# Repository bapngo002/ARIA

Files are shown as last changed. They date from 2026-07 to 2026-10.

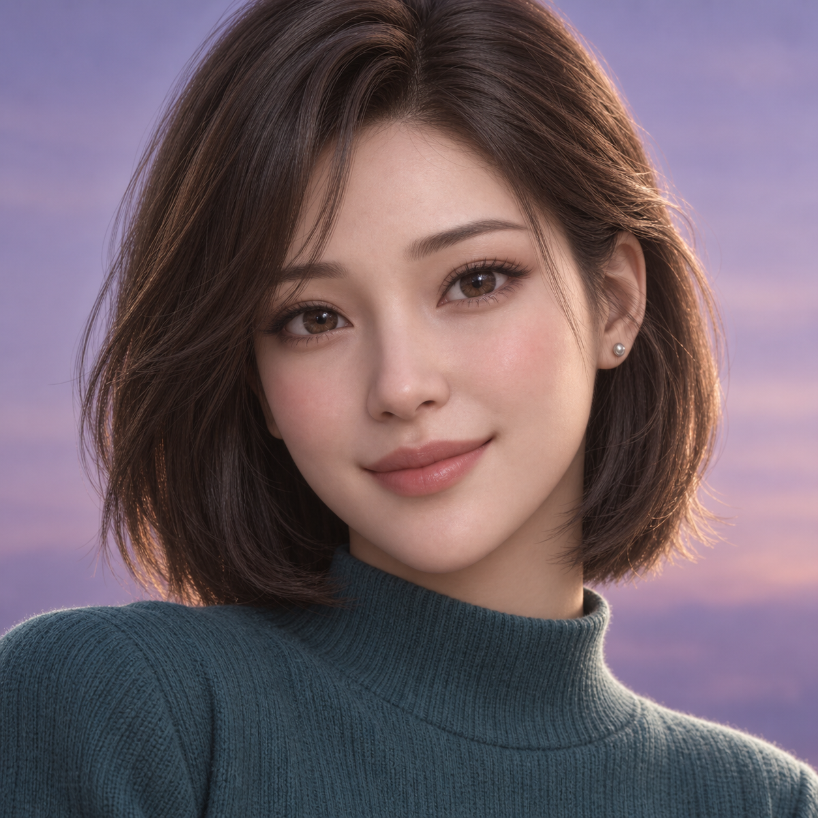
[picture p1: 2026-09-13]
docs/design/aria-face-concepts/03-bob.png

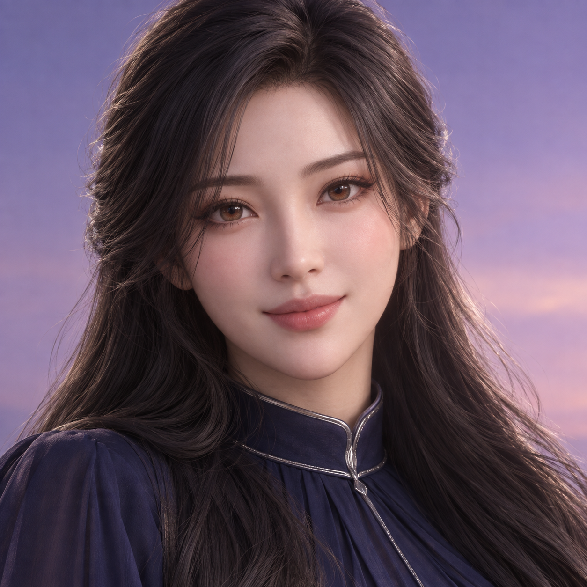
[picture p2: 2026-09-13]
docs/design/aria-face-concepts/01-long-hair.png

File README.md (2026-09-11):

# ARIA

ARIA là dự án robot AI đồng hành cá nhân.

**Bắt đầu tại [ARIA-MASTER-HANDOFF](docs/ARIA-MASTER-HANDOFF.md)**: CURRENT/CANONICAL snapshot, hướng dẫn tài khoản ChatGPT mới, tiến độ kiểm chứng, pinmap, migration gaps và NEXT STEP ORDER. Checkout đã hợp nhất là source of truth làm việc; trạng thái đồng bộ GitHub xem master.

[ARIA-BOM-001](docs/ARIA-BOM-001.md) là nguồn duy nhất cho inventory, model, số lượng, trạng thái mua và CAD. Không suy ra tiến độ từ BOM. CAD/bằng chứng mua hàng nằm trong `purchased-hardware/`.

[PRD](docs/ARIA-PRD-001.md) giữ frozen cho yêu cầu sản phẩm; các ghi chú tiến độ cũ trong đó không thay thế master handoff. Đã nhập 9 file capture Pi/ESP32 nguyên bản; runtime và build vẫn cần xác minh; xem checklist ở master, [firmware](firmware/README.md) và [software](software/README.md).

Dữ liệu ARIA lưu trên ổ D. Repo làm việc: `D:\UserData\ARIA\repo`; chính sách lưu trữ và đường dẫn lịch sử xem master handoff.

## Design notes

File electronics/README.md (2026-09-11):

# ARIA electronics workspace

Native mainboard, schematic and reviewed fabrication work belongs here.

Do not store another component list or CAD library here. Use [`docs/ARIA-BOM-001.md`](../docs/ARIA-BOM-001.md) for the purchased inventory and CAD status.

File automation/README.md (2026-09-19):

# ARIA Automation

Canonical state and architecture: `docs/ARIA-AUTOMATION-CANONICAL.md`.

Runtime state is kept outside Git at `D:\UserData\ARIA\automation-state`.

Phase 1 commands:

```powershell
powershell -NoProfile -ExecutionPolicy Bypass -File .\automation\windows\aria-c2c.ps1 Status
powershell -NoProfile -ExecutionPolicy Bypass -File .\automation\windows\aria-c2c.ps1 Ensure
powershell -NoProfile -ExecutionPolicy Bypass -File .\automation\windows\install-c2c-startup.ps1
powershell -NoProfile -ExecutionPolicy Bypass -File .\automation\tests\test-phase1.ps1
```

Phase 2 one-shot runner:

```powershell
powershell -NoProfile -ExecutionPolicy Bypass -File .\automation\runner\aria-runner.ps1 -TaskText "Review current PRO MAX power state"
powershell -NoProfile -ExecutionPolicy Bypass -File .\automation\runner\aria-runner.ps1 -TaskFile .\task.json
powershell -NoProfile -ExecutionPolicy Bypass -File .\automation\runner\aria-runner.ps1 -ResumeTaskId aria-YYYYMMDDTHHMMSS-xxxxxxxx
powershell -NoProfile -ExecutionPolicy Bypass -File .\automation\tests\test-phase2.ps1
```

Phase 2 task packets are untracked runtime data under `automation/runtime/tasks/<task_id>`. See `automation/runner/README.md` for the state machine and packet contract.

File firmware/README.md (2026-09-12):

# ARIA firmware

Mới 2026-09-13: [ARIA_ENCODER_CHECK_R1](esp32/ARIA_ENCODER_CHECK_R1/README.md) v0.1.0, chỉ kiểm tra encoder phải SDA4/SCL5 trên ESP thay thế. Không chạy motor; giữ nguồn driver ngắt. Encoder trái hỏng để tách khỏi mạch. Đây là bản riêng, không sửa capture dưới đây.

Đã nhập nguyên bản [ARIA_DRIVE_ONLY.ino](esp32/ARIA_DRIVE_ONLY/ARIA_DRIVE_ONLY.ino), banner Drive V0.3. Đây là source capture, chưa xác minh flash hoặc last-known-good. Không sửa pin/tuning hoặc tự flash trong đợt hợp nhất.

[MASTER HANDOFF](../docs/ARIA-MASTER-HANDOFF.md) là nguồn duy nhất cho pinmap, motor PARTIALLY VERIFIED, các nhánh watchdog còn mở và checklist build/bench. Hash nằm trong [capture manifest](../software/capture-manifest.json).

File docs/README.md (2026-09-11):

# ARIA engineering documents

**Đọc [ARIA-MASTER-HANDOFF.md](ARIA-MASTER-HANDOFF.md) trước.** Đây là snapshot CURRENT/CANONICAL về tiến độ, verification, pinmap và migration gaps; checkout đã hợp nhất là source of truth làm việc; trạng thái đồng bộ GitHub xem master.

[`ARIA-BOM-001.md`](ARIA-BOM-001.md) là nguồn chuẩn duy nhất cho inventory, model, số lượng, trạng thái mua và CAD. Không suy diễn tiến độ từ BOM. PRD giữ frozen; ghi chú tiến độ historical trong PRD không phải current-state.

| File | Nội dung |
|---|---|
| `ARIA-MASTER-HANDOFF.md` | CURRENT/CANONICAL tiến độ, bootstrap, evidence, pinmap, gaps và next steps |
| `ARIA-BOM-001.md` | Inventory và CAD canonical |
| `ARIA-PRD-001.md` | Yêu cầu sản phẩm frozen |
| `ARIA-HW-001.md` | Cổng kiểm tra phần cứng |
| `ARIA-MECH-001.md` | Quy tắc cơ khí/CAD |
| `ARIA-PCB-001.md` | Quy tắc phát triển mainboard |
| `ARIA-WIRING-001.md` | Quy tắc đấu dây và an toàn |

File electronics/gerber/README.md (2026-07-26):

# Gerber release directory

Only reviewed fabrication packages belong here. Each release must identify its
source commit, PCB revision, DRC result, and user approval.

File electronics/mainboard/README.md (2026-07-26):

# Mainboard

Native source files for the two-layer ARIA mainboard. Development is governed by
`docs/ARIA-PCB-001.md`.

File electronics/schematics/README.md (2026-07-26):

# Schematics

Reviewed schematic exports, power-tree diagrams, calculations, and design-review
records.

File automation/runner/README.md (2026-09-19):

# ARIA One-Shot Runner — Phase 2

`aria-runner.ps1` is the single Phase 2 intake entrypoint. It accepts one task, creates one durable packet, advances the fixed state machine, and prints one aggregate JSON report. Phase 2 always stops before routing, council, Codex execution, or repository execution.

## Commands

Task text:

```powershell
powershell -NoProfile -ExecutionPolicy Bypass -File .\automation\runner\aria-runner.ps1 -TaskText "Review current PRO MAX power state"
```

The task text can also be positional:

```powershell
powershell -NoProfile -ExecutionPolicy Bypass -File .\automation\runner\aria-runner.ps1 "Review current PRO MAX power state"
```

JSON input:

```json
{
  "user_request": "Review current PRO MAX power state",
  "workspace": "D:\\UserData\\ARIA\\repo",
  "scope": "review"
}
```

```powershell
powershell -NoProfile -ExecutionPolicy Bypass -File .\automation\runner\aria-runner.ps1 -TaskFile .\task.json
```

Resume after interruption or a corrected transient failure:

```powershell
powershell -NoProfile -ExecutionPolicy Bypass -File .\automation\runner\aria-runner.ps1 -ResumeTaskId aria-YYYYMMDDTHHMMSS-xxxxxxxx
```

## Durable packet

Each task is stored under `automation/runtime/tasks/<task_id>/`:

- `task.json`: the normalized request and immutable task digest.
- `checkpoint.json`: authoritative resumable stage state.
- `events.jsonl`: bounded append-only transition evidence; raw task text is not copied here.
- `final-report.json`: the single aggregate output for the latest attempt.

Writes to `task.json`, `checkpoint.json`, and `final-report.json` use same-directory temporary files and atomic replacement. A per-task lock prevents concurrent attempts. The checkpoint is authoritative if power loss occurs between file writes. A resumed invocation verifies the immutable task digest before continuing.

The Phase 2 state machine is fixed in `stage-schema.json`:

```text
RECEIVED -> CONTEXT_LOAD -> PRECHECK -> READY_FOR_ROUTING -> STOP
```

Any failure records `FAILED`, enters `STOP`, preserves the failed stage in `resume_stage`, writes a final report, and exits with code 2. A successful run exits with code 0 and result `READY_FOR_ROUTING`. `STOP` is a boundary in this phase, not permission to route or execute.

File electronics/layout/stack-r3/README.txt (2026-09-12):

ARIA STACK R3 — CONCEPT FOR SOLIDWORKS VIEWING

Open ARIA_STACK_R3_ASSEMBLED_CONCEPT.step or ARIA_STACK_R3_EXPLODED_CONCEPT.step in SolidWorks (File > Open > STEP). Native FreeCAD sources are also provided. Native SLDPRT export was not verified because the installed SolidWorks COM startup did not return; no claim of successful SolidWorks import is made.

Units: mm. Base outline: 70 x 100, confirmed by user. Overall assembled concept envelope: approximately 70 x 120 x 79.6; the additional length is ESP antenna overhang. Layer elevations 0 / 30 / 60 are design assumptions, NOT selected standoff heights. Module blocks, connectors and cooler are representative envelopes, NOT dimensionally validated library parts. The Pi nominal outline and ESP nominal outline are used for illustration, not footprint release. No mounting-hole coordinates are released. The rear Pi support scheme is deliberately incomplete pending actual mounting geometry.

Green: carrier/board. Black: ESP, driver or ground bank. Purple: amplifier. Orange: power-module placeholder. Blue: INA260 or sensor connector. Front banks are physically adjacent but electrically distinct: GND / VBAT / 5V / 3V3_PI / 3V3_ESP. These are not connector part selections or a circuit diagram.

The exploded model raises middle and top levels by 32 and 64 mm beyond their assembled positions. No motion, firmware changes, electrical continuity, thermal/EMI test or assembly-fit release has been performed. All exported shapes passed geometric validity checks; PNGs were visually reviewed. Geometry validity does not prove mechanical fit.

Functional mounts (display, camera, ToF, mic, IMU/environment, battery/motors/speakers) remain outside this electronics-stack concept. INA260 label is visible in the user photo; its arrival/use and wiring are not yet confirmed. Keep the burned board and suspect harness unpowered until incident checks.

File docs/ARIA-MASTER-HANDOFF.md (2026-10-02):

# ARIA — MASTER HANDOFF

## ACTIVE CHECKPOINT - 2026-10-02 S5 HEALTH MANAGER TECHNICAL PASS PC; STOP owner decision

- **Current: S5 HEALTH MANAGER = TECHNICAL_PASS_PC; STOP owner next decision.** HealthManager is the single evidence/normalization/publication owner for APP/AVATAR/VOICE/STT/TTS/AUDIO/CAMERA/ESP/POWER/NETWORK/AI. Seven existing states unchanged; HOLD not implemented.
- **PC proof:** 147 backend + 4 real loopback HTTP health/security + 85 frontend tests PASS; 28 browser cases PASS, including real MaiChi playback/end/cancel -> REST and normalized TTS/AUDIO/VOICE health. Camera delta=0, avatar reload=0, uncaught exceptions=0. No new render loop/canvas/WebGL/health worker/timer.
- **Stress:** 3,000 transition cycles -> 9,000 health events; 10,000 unchanged reports -> 0 events. Retained backend memory +884 bytes, listeners/thread count unchanged, bounded ring256; UI30 cycles DOM347->347/listeners184->184/post-GC nodes958->958.
- **Health policy:** monotonic evidence leases; stale -> UNKNOWN/stale=true; disabled != offline != fault. Nonfatal first failure from HEALTHY grace3s, second DEGRADED, third FAULT; actual success recovers. APP/fatal evidence immediate; explicit POWER danger latched until success. Optional camera/ESP do not fault overall app. HTTP liveness cannot clear composition fault; browser cannot own APP health; fixture reports rejected.
- **Current evidence limits:** APP TTL5s, AVATAR120s, POWER5s, configured ESP1.5s, NETWORK60s, others300s. Avatar readiness has a conservative lease without a new heartbeat. Real physical power/camera/ESP, STT capture, Pi CPU/FPS and service benchmark remain unverified/DEFERRED_PI; not production verified.
- **S4-06 owner decision:** TECHNICAL_PASS_PC / VISUAL_PASS_CONDITIONAL. Hardware Aura visual locked, CAMERA OFFLINE visibility=POLISH_LATER. Production Aura consumes normalized health; labelled health fixtures are frontend-only tests, not telemetry.
- **Evidence/checkpoint:** D:/UserData/ARIA/SPATIAL_OS_WORK/reports/S5-HEALTH-MANAGER/{report.md,checkpoint.json}; captures/S5-HEALTH-MANAGER contains genuine production-health and MaiChi proof plus labelled test fixtures. Source/capture SHA-256 and exact changed-file scope recorded. UI40 and other protected35 hashes unchanged.
- **Preserved:** native primary/default; ZeroWeight experimental; temporary MaiChi RMS voice/Piper retained. No .blend/GLB/master copies or changes, no PCB/ESP transport/firmware/motor action. S5 health code/assets remain LOCAL; only this reviewed checkpoint synchronized. No reset/revert/broad staging.
- **NEXT STEP: STOP. Owner decides next stage; no S6/S7, no Memory Constellation. Pi DEFERRED_PI.**

## Earlier checkpoints - retained as history

## ACTIVE CHECKPOINT - 2026-10-02 S4-06 TECHNICAL PASS PC; VISUAL EVIDENCE READY; STOP owner review

### S4-06 Hardware Aura - TECHNICAL PASS PC - 2026-10-02

- **OWNER DECISION/SCOPE:** S4-05 TECHNICAL_PASS_PC / VISUAL_PASS_CONDITIONAL accepted; freeze accepted Home/Capability Field, POLISH_LATER only. S4-06 only; STOP for owner visual review, NO S4-07. Pi DEFERRED_PI.
- **IMPLEMENTATION:** existing AppStore app.health drives seven bounded SVG arcs POWER/AUDIO/STT/CAMERA/ESP/NETWORK/AI; exact seven aria_state.py health states, unknown/missing/disconnected safe. SYSTEM_AURA semantic layer between CONTEXT/FOREGROUND; context recedes normal arcs, fault remains visible. Hover/tap/keyboard micro info,4200ms auto-dismiss, no permanent text. Real voltage only existing non-mock matching fresh backend power.latest source/schema; absent telemetry no number. STARTING pulse two700ms cycles only on state change; LOW_POWER/reduced motion static/cancel active pulse.
- **VERIFY:**85 targeted tests(17 new+68 retained),3 JS syntax checks;26 aggregate browser cases(16 production+8 edges+2 real MaiChi voice).480x480/720x720/current1536x1039,mouse/touch,all five context ports,30 health cycles DOM349->349/listeners184->184/retained nodes962->962 after GC;heap7020572->7027744 bytes.10 factory destroy/re-init cycles clean. Camera0,avatar reload0,uncaught0,finite morphs,same native canvas/single loop. No new poll/render loop/canvas/WebGL.
- **PRESERVED/LIMITS:**40 protected asset/avatar/voice hashes and28 backend hashes unchanged;36 existing UI sources unchanged; accepted46965-byte S4-05 CSS prefix exact. Three existing UI files(app.js/style.css/spatialLayers.js)+new hardwareAura.js+one test changed; code/assets LOCAL. Native primary,ZeroWeight experimental,MaiChi temporary RMS/Piper fallback retained. Genuine MaiChi playback across five contexts -> end REST;actual Media stop -> cancel REST. Full suite/live STT/camera/physical telemetry/Piper playback/Pi FPS not claimed. One favicon404 console resource error disclosed,0 JS exceptions.
- **EVIDENCE:** D:/UserData/ARIA/SPATIAL_OS_WORK/reports/S4-06/{report.md,checkpoint.json,webgl.json,edges.json,voice.json,preservation.json,scope-audit.json,visual-evidence.json};captures/S4-06/review-sheet-720.png. Seven labelled frontend health fixtures on genuine production app/native GLB plus one actual PC health image; no backend health/telemetry writes. Full720 originals, no crop/filter/color changes.
- **STATUS/NEXT:** TECHNICAL_PASS_PC / VISUAL_EVIDENCE_READY / PENDING_OWNER_REVIEW. STOP here; NO S4-07 or Pi. Review Hardware Aura sheet; small S4-05 polish deferred. Documentation-only reviewed synchronization; preserve dirty tree.

## Earlier checkpoints - retained as history

## ACTIVE CHECKPOINT - 2026-10-02 S4-05 TECHNICAL PASS PC; VISUAL EVIDENCE READY; STOP owner review

### S4-05 Spatial Depth & Visual Language - TECHNICAL PASS PC - 2026-10-02

- **OWNER REVIEW/SCOPE:** IDLE retained as accepted baseline; earlier HOME/CHAT visual FAIL and field-depth FAIL prompted this bounded UI change. S4-01–04 technical PASS retained. No backend/avatar/voice/model/hardware feature opened.
- **RESULT:** latest user/ARIA current-turn strips replace permanent full-history panel; inactive turn DOM removed after20s attention. Explicit history uses same single-owner context lifecycle. Mic command dock tap/type expansion, successful-send collapse, unsent draft retention, max2 transient suggestions. Five asymmetric capability objects have distinct CSS Z-depth/scale/opacity, local material/rims and focus advancement; native camera unchanged. Two static background layers, consistent large avatar, healthy provider text hidden on main.
- **VERIFY:**68 targeted/regression tests+4 syntax checks;34 aggregate browser cases(11 production+23 edge),30-cycle all-port cleanup DOM318->318;480/720/current1536x1039/mouse/touch. Camera0,avatar reload0,uncaught0,finite real blink/gaze/mouth/seven visemes,single native loop. New UI transform/opacity;observed targets max7;LOW_POWER perspective off. Dispatch and voice-state fixtures labelled,not new real audio proof. Native short meter quiet28.44FPS/field~29FPS under retained30FPS cap,NOT Pi/60FPS benchmark.
- **PRESERVED/LIMITS:**40 protected hashes+40 other UI-source hashes unchanged. Six UI source files and one targeted test changed; code/assets LOCAL. Native primary,ZeroWeight experimental,MaiChi temporary RMS/Piper fallback retained. Full suite/live audio/STT/send/camera/media not rerun;favicon404 disclosed separately. Pi DEFERRED_PI. No source/master/runtime change or copy.
- **EVIDENCE/STATUS:**D:/UserData/ARIA/SPATIAL_OS_WORK/reports/S4-05/{report.md,checkpoint.json,webgl.json,edges.json,lifecycle_trace.json,preservation.json,visual-evidence.json};captures/S4-05 eight genuine production720 PNGs+review-sheet-720.png,viewport captures. TECHNICAL_PASS_PC;VISUAL_EVIDENCE_READY;PENDING_OWNER_REVIEW. Agent inspection recorded;NO VISUAL_PASS.
- **NEXT:**STOP for owner review of review-sheet-720.png. NO S4-06/Hardware Aura/Memory Constellation/Pi. Documentation-only reviewed sync; preserve dirty working tree.

## Earlier checkpoints - retained as history

## ACTIVE CHECKPOINT - 2026-10-02 VISUAL EVIDENCE READY; STOP owner review

### S4-03/S4-04 Production Visual Evidence Gate - 2026-10-02

- **STATUS:** S4-03 = TECHNICAL_PASS_PC; S4-04 = TECHNICAL_PASS_PC; VISUAL_APPROVAL_PENDING. VISUAL_EVIDENCE_READY; VISUAL_GATE = PENDING_OWNER_REVIEW. No owner visual PASS claimed.
- **FIX/VERIFY:** Capture helper's serialized DOM lacked getAnimations despite correct element lookup; genuine Chromium154 supports it. Evidence-only feature detection, bounded transition fallback and full Home fade wait added; production UI unchanged.24 real production PNGs at720x720/480x480/current1536x1039, eight requested states each; no DEV overlay/mock/test page.60 lifecycle events: max active1,DOM323->323,empty closed host,avatar reload0/camera delta0/uncaught0/lifecycle errors0,same native canvas/loop. One initial favicon.ico404 disclosed separately.
- **PRESERVED/EVIDENCE:**45 production source hashes unchanged;40 protected hashes match prior checkpoint. Native primary/Mai Chi temporary/Piper fallback retained. Existing technical suites not rerun. D:/UserData/ARIA/SPATIAL_OS_WORK/reports/S4-04/visual-gate.md, visual-capture.json, visual-lifecycle-trace.json; captures/S4-04/visual-gate/{720x720,480x480,current_1536x1039}/01_home_idle.png through08_return_home.png.
- **NEXT:** STOP for owner screenshot review. S4-05/Hardware Aura/new redesign unopened; Pi DEFERRED_PI. Only this reviewed handoff delta published; code/assets remain LOCAL.

## Earlier checkpoints - retained as history

## ACTIVE CHECKPOINT - 2026-10-02 S4-04 all five context ports PASS PC; owner visual pending

Native primary; Mai Chi temporary RMS voice unchanged; no hardware. Code/assets LOCAL; documentation only.

### S4-04 Remaining Capability Context Ports - TECHNICAL PASS PC - 2026-10-02

- **RESULT:** Messages/Camera/Media/Settings now register CONTEXT surfaces through the SAME S4-03 manager, alongside Memory. One host/owner; no new popup, renderer or page navigation. Draft restore for Memory/Messages, app-state for Camera/Media and preferences for Settings. Existing handler/backend mapping retained; unavailable camera stays disabled. No redesign; only capabilityField registry/policy/comment changed in this stage.
- **VERIFY:** 62 targeted/regression tests and58 browser cases PASS: all five at480/720/current2138x1033/360x740; all20 ordered replacements, canonical Escape/Close, draft restore, all-port LISTENING prominence fixtures, production touch/captures. Existing Messages/Camera/Media/Settings handler dispatch isolated locally, without send/capture/external launch/config mutation. Real unchanged Mai Chi playback while replacing all five contexts -> end REST; actual Media surface stop -> cancel REST.0 exceptions/NaN,camera delta0,native reload0 during surface operations; same canvas/render loop.
- **PRESERVED/LIMITS:**40 forbidden hashes exact;8 other S4-03 UI/core hashes unchanged, including lifecycle manager/CSS/apps. S4-03 30-cycle stress/no DOM-listener growth retained;20 new cross-capability replacements cleanup PASS. Native primary, experimental ZeroWeight, temporary Mai Chi RMS-only/Piper fallback, source/master/GLB/backend/hardware unchanged; no source/candidate copy. Owner visual PENDING, Pi DEFERRED_PI; full project suite/live camera/STT/send/media playback not claimed.
- **EVIDENCE/NEXT:** reports/S4-04/{report.md,checkpoint.json,webgl.json,voice.json,lifecycle_trace.json,preservation.json,visual_review.json}; captures/S4-04 all ports/viewport/production-touch/actual voice PNGs. Code/UI LOCAL; reviewed documentation-only sync. Core context lifecycle and five ports technically complete on PC; retain for owner final visual review. No Hardware Aura or Pi task opened.

## Earlier checkpoint records - retained as history

## ACTIVE CHECKPOINT - 2026-10-02 S4-03 Context Lifecycle PASS PC; S4-04 next

Native primary; Mai Chi temporary RMS voice unchanged; no hardware. Code/assets LOCAL; documentation only.

### S4-03 Context Surface Lifecycle - TECHNICAL PASS PC - 2026-10-02

- **RESULT:** spatialSurfaces.js now owns one foreground context through CLOSED/ENTERING/ACTIVE/EXITING/CLOSED, latest-request replacement, canonical Close/Escape/Browser Back and explicit owner/dismiss/restore policies. Listening reduces prominence without deleting draft; no SUSPENDED state required. Finite220ms enter/180ms exit; LOW_POWER120/100ms; reduced motion immediate. Semantic CONTEXT layer sits between retained avatar CENTER alias and foreground/alert layers; no redesign or new renderer.
- **CLEANUP:** closed host body empty; generated Memory rows/listeners released, transition timer/animation/session scope0. Original lightweight form controls/handlers are parked as bounded reusable view templates to preserve drafts; no newly hidden heavy presentation retained or per-open listener added. App-lifetime listeners are abortable on destroy; trace is capped at96 metadata entries.
- **VERIFY:** 62 targeted/regression tests; 71 browser cases PASS, including30 actual-click open/API replace/close cycles,10 rapid sequences, Browser Back, LISTENING/IDLE draft fixture, touch,480/720/current2138x1033, real unchanged Mai Chi WAV speaking/context replace/end/cancel REST.0 JS exceptions/NaN;camera delta0;native reload0 and same canvas/render loops. DOM/listener counters {'documents': 1, 'nodes': 938, 'jsEventListeners': 137} -> {'documents': 1, 'nodes': 938, 'jsEventListeners': 137}; live nodes 338 -> 338; heap delta308648bytes after controlled GC, no linear growth in samples.
- **FIXES/LIMITS:** delayed backend open could reopen during EXITING; UI close intent now begins at EXITING, serial navigation waits for request acknowledgement plus matching state. Real400ms delayed-response proof PASS. Test-only standby/reload reference errors corrected; retained failure evidence.40 forbidden hashes exact; assets/avatar/voice/backend/hardware untouched. Native primary, experimental ZeroWeight, temporary Mai Chi RMS/Piper retained. Owner visual PENDING; Pi DEFERRED_PI; full suite not run, no mic/STT or phoneme timing claim.
- **EVIDENCE/NEXT:** reports/S4-03/{report.md,checkpoint.json,webgl.json,edges.json,lifecycle_trace.json,preservation.json}; captures/S4-03 real context/listening fixture/voice/controls/touch PNGs. Code/assets LOCAL; documentation-only sync. NEXT automatically S4-04 port remaining four capabilities to this same context manager. No Hardware Aura.

## Earlier checkpoint records - retained as history

## ACTIVE CHECKPOINT - 2026-10-02 S4-02 Memory context PASS PC; field retained

Native primary; Mai Chi temporary RMS voice unchanged; no hardware. Code/assets LOCAL; documentation only.

### S4-02 Memory context surface - PASS PC - 2026-10-02

- **RESULT:** S4-01 accepted field retained; Memory now uses a real CONTEXT surface bound to existing AppStore memories/remember controls, rather than web-page navigation. Native avatar remains visible with unchanged accepted camera. Draft stays in its existing input; entry uses finite transform/opacity only. Reading an active context no longer triggers30s standby. Memory composer is fixed in the surface; content/destructive control scroll independently.
- **SAFETY/UX:** existing cancel action is reachable via compact surface stop while busy; no TTS/backend rewrite. Close clears context/active/tint/description and restores focus/home interaction. Existing Messages/Camera/Media/Settings TASK surfaces remain accessible. Alert band reserved below surfaces; footer recedes only when a notice occupies that band, preventing overlap on small circles.
- **VERIFY:** 51 targeted/regression tests,32 actual WebGL context cases+2 final audio/UI+20 final layout cases PASS (54 total),480/720/current1368x1027 and360x740. Real unchanged Mai Chi speaking -> end REST, and actual /api/cancel200 -> tts:end(ok=false) -> mouth/UI REST;31s context reading,touch,draft,reload,cleanup and all five surface selections.0 JS exceptions/NaN;camera delta0;avatar/canvas/load/render-loop unchanged. Remember dispatch and replayed existing alert are labelled isolated UI fixtures; no saved owner record/send/camera/external launch.
- **PRESERVED/LIMITS:**40 protected hashes exact; source/master/runtime/manifest/engine/FaceRig/gaze/blink/mouth/backend/voice/hardware untouched. Native primary; ZeroWeight experimental; temporary Mai Chi RMS-only and Piper fallback retained. Same source file,no candidate copy. Owner artistic approval and actual Pi performance remain pending; S3-17 DEFERRED_PI. Existing inherited aplay notice is displayed honestly, not a new voice fix. Full project suite not run.
- **EVIDENCE/NEXT:** reports/S4-02/{checkpoint.json,webgl.json,final_ui.json,layout_final.json,preservation.json,visual_review.json,report.md}; captures/S4-02 actual Memory/voice/end/cancel/touch/production field PNGs. Code/UI LOCAL; reviewed documentation-only sync. NEXT S4-03 capability stop/cancel/return lifecycle per existing roadmap; no S5/Pi/hardware task opened.

## Earlier checkpoint records - retained as history

## ACTIVE CHECKPOINT - 2026-10-02 S4-01 Capability Field PASS PC; S4-02 context next

Native primary; Mai Chi temporary RMS voice unchanged; no hardware. Code/assets LOCAL; documentation only.

### S4-01 Capability Field - PASS PC - 2026-10-02

- **OWNER SCOPE OVERRIDE:** owner explicitly opened S4-01 PC UI despite deferred S3-17/Pi and pending owner visual gates. Historical no-S4 notes remain history; no Pi/SSH/deploy or hardware task opened.
- **RESULT:** five fixed Messages/Camera/Memory/Media/Settings nodes on an avatar-centered arc; muted teal/violet/gold/coral/ice-blue, restrained perspective/focus depth. Four tabs and app grid removed. Existing forms/actions open through spatialSurfaces while native canvas stays mounted; no page navigation or second renderer. Closed/inert cleanup, Escape/outside/keyboard/touch, LOW_POWER and reduced-motion supported.
- **VERIFY:** 51 targeted/regression tests, 104 UI/WebGL plus9 edge cases PASS;30 open/close cycles,480/720/current1368x1027 and360x740, all five selections, keyboard/touch, delayed backend open/close, reload and retained unsent draft.0 JS exceptions/NaN; accepted camera delta0; same avatar/canvas/load count/render loop. Real unchanged Mai Chi playback continues while field opens/closes and ends REST; real retained gaze/mouth/seven visemes verified.
- **PERFORMANCE/PRESERVED:** PC UI requestAnimationFrame cadence143.997Hz over5s,p95 interval7.1ms; this is UI cadence, NOT native-avatar FPS or Pi measurement. Existing Balanced native cap remains30FPS.40 protected hashes exact: source/master/runtime/manifest/avatar controllers/FaceRig/voice/backend untouched. Native default, experimental ZeroWeight, temporary Mai Chi RMS voice and Piper fallback retained. No source/candidate copy.
- **EVIDENCE/NEXT:** reports/S4-01/{checkpoint.json,webgl.json,edges.json,preservation.json,visual_review.json,report.md}; captures/S4-01 genuine before/after/focus/surface/touch/voice PNGs. Agent visual PASS; owner visual and Pi pending; unavailable STT/camera/media stay truthful. Code/UI LOCAL, reviewed documentation-only sync. Next automatically S4-02: connect Memory to a dedicated context surface using the accepted field; no unrelated feature.

## Earlier checkpoint records - retained as history

## ACTIVE CHECKPOINT - 2026-10-02 PC interface PASS with Pi deferred by owner

Native primary; Mai Chi temporary RMS voice unchanged; no hardware. Code/assets LOCAL; documentation only.

### PC interface completion - PASS AGENT VISUAL / RUNTIME; Pi DEFERRED_BY_OWNER - 2026-10-02

- **OWNER PRIORITY:** PC interface first. S3-17 Pi/IP/aria.local/SSH/deploy is DEFERRED_PI, not PASS. S3-12 through S3-16 technical PASS retained; no rebuild/retest from start. S3-18 full owner/Pi gate remains unfulfilled; no S4/S5 or hardware opened.
- **UI RESULT:** circular home with larger native avatar and reserved conversation/composer space; consistent ink background/type/spacing, local icons for mic/send/stop/quick actions; menu overlays without pushing content. Settings/memory/apps scroll inside the circle. DEV tools collapse into an explicit drawer, absent on production URL. Native canvas and user-facing capabilities no longer say placeholder/missing morph. Semantic hidden is enforced, fixing inherited return/action controls leaking into UI.
- **VERIFY:** 51 targeted/regression tests (8 new UI truthfulness tests), 48 actual UI/WebGL cases across360/480/720 and1280x900. Accepted camera transform/FOV delta0; no JS exception/NaN/stuck mouth. Real unchanged Mai Chi utterance -> mouth -> end REST; actual chat UI -> playback -> stop -> REST. PC20s observation28.795FPS Balanced, NOT Pi evidence. Genuine before/after PNGs, all four state layouts and avatar controls; agent visual PASS, owner artistic acceptance still PENDING.
- **PRESERVED:** SAME source models/S3-07/ARIA_AVATAR_MOUTH_CANDIDATE_v1.blend SHA1f1dcab26696fa6eef413e381454ebaf86f2aaffdbbae64fdb03356bf79eca71; native63,097,656byte LOD runtime SHAc6ac88d11de7c883558996766efed8ae5e80485ed576305c698f190a2e04065a and manifest unchanged. Original master/geometry/33bones/blink/gaze/head/mouth/viseme/camera lighting/voice backend unchanged. AvatarEngine change is accessible canvas label only. Mai Chi temporary RMS-only/Piper fallback retained; ZeroWeight experimental unchanged.
- **EVIDENCE/SCOPE:** SPATIAL_OS_WORK/reports/UI-PC/{checkpoint.json,webgl.json,interaction.json,visual_review.json,preservation.json,targeted_regression.log,report.md}; captures/UI-PC real PNGs. Code/UI/assets stay LOCAL; reviewed documentation-only sync. Existing8765 launcher had no TTS config; user tab now uses unchanged existing Mai Chi PC server http://127.0.0.1:8790/ (no services/hardware started), native primary, DEV off. Micro/STT unavailable is shown honestly; no STT/cloud/camera capability claim.
- **FIXED FAILURES:** menu route attribute initially collided with navigation selector, corrected; test fixtures isolated from live SSE polling (production unchanged); five old circular tests used retired property names, corrected to current public API without geometry change. Full project suite not run. NEXT retain this PC UI checkpoint for visual feedback; complete remaining PC UX issues if observed before expanding phase scope. Pi stays deferred until owner changes that decision; latest quota52% remaining.

## Earlier checkpoint records - retained as history

## ACTIVE CHECKPOINT - 2026-10-02 S3-17 Pi access blocked; S3-12 through S3-16 PC PASS retained

Native primary; Mai Chi temporary RMS voice unchanged; no hardware. Code/assets LOCAL; documentation only.

### S3-17 real Pi gate - BLOCKED ACCESS; PC S3-12 through S3-16 RETAINED PASS - 2026-10-02

- **ACTUAL ACCESS EVIDENCE:**after S3-16 PASS,read-only check of documented endpoint aria@aria.local. DNS failed `[Errno 11001] getaddrinfo failed`; non-interactive strict-host-key SSH exit255,no identity output. No alternative Pi IP documented in current master. reports/S3-17/access_probe.json andcheckpoint.json. No Pi benchmark,remote file write,service start or hardware action; not Pi performance PASS.
- **RETAINED:**S3-12/13/14/15/16 PC PASS,active native LOD290331tris/63097656bytes SHAc6ac88d11de7c883558996766efed8ae5e80485ed576305c698f190a2e04065a; source SHA1f1dcab26696fa6eef413e381454ebaf86f2aaffdbbae64fdb03356bf79eca71 SAME file retained.106avatar/74backend/76 S3-15+16 WebGL PASS,camera/bounds/layout0. User DEV tab reloaded,Native3D retained. Mai Chi temporary RMS-only voice frozen,real PC playback/end REST regression PASS; Piper fallback retained; ZeroWeight experimental unchanged.
- **NEXT:**owner asked only for current Pi5 IP/hostname to resolve actual access blocker; verify target identity/model/RAM read-only first,then S3-17 real standalone Pi benchmark. Do not use PC FPS as Pi proof,start aria-core/motor/ESP services or open S4. S3-18 depends actual Pi runtime/audio and owner visual acceptance. Owner voice/lip-sync review tomorrow pending. Latest quota remaining56%,stop is access blocker,not quota. Code/config/assets local; documentation-only sync.

## Earlier checkpoint records - retained as history

## ACTIVE CHECKPOINT - 2026-10-02 S3-12 through S3-16 PC PASS; S3-17 real Pi next

Native primary; Mai Chi temporary RMS voice unchanged; no hardware. Code/assets LOCAL; documentation only.

### S3-16 framing/visual regression - PASS PC - 2026-10-02

- **COMPLETE:**S3-12 natural idle->S3-13 offline LOD->S3-14 export/reimport->S3-15 native runtime->S3-16 PC visual/framing all sequential PASS. Same active models/S3-07/ARIA_AVATAR_MOUTH_CANDIDATE_v1.blend SHA1f1dcab26696fa6eef413e381454ebaf86f2aaffdbbae64fdb03356bf79eca71; no new source copy,LOD source not saved/overwritten. Runtime aria-avatar-idle-lod-runtime.glb SHAc6ac88d11de7c883558996766efed8ae5e80485ed576305c698f190a2e04065a,63097656bytes,290331tris; previous expression runtime retained. Native default; ZeroWeight experimental unchanged.
- **PROOF:**16 real WebGL before/after comparison cases REST/A/F_V/blink/gaze/head/reset. Camera delta0,bounds delta0,canvas layout delta0,and historical S3-06 accepted camera delta0. Protected sampled facial vertex delta<1e-7; visual region mean pixel delta<.058/255,p95=0. Face/hair/REST/facial motion retained; existing closeup shading remains baseline quality,owner artistic approval pending.33bones,7visemes,mouth/incisors,independent gaze/blink/expressions retained.106avatar/74backend/60 S3-15 WebGL plus16 S3-16 cases PASS; not full project/Pi PASS.
- **VISIBLE APP/EVIDENCE:**current user Chrome DEV8790/?dev=1 reloaded; native asset READY,290331 triangles observed via CUA state+actual screenshot; no provider/default change. reports/S3-16/framing.json,visual_review.json,checkpoint.json and actual source/LOD face/app captures; S3-12/15 real120s idle videos retained. Mai Chi TEMPORARY_VOICE_ACCEPTED_FOR_NOW,RMS-only frozen,actual regression plays/ends REST; Piper remains. Voice review tomorrow; inherited aplay error1 UI history unchanged,not a new voice change.
- **NEXT/PENDING:**S3-17 real Pi5/4GB performance gate,begin with read-only target identity/access check; no PC-to-Pi performance inference. S3-18 requires owner visual+Pi runtime/audio gates; do not open S4. No motor/encoder/driver/core-service action. Code/config/assets remain LOCAL; reviewed documentation-only GitHub sync.

## Earlier checkpoint records - retained as history

## ACTIVE CHECKPOINT - 2026-10-02 S3-15 native LOD runtime PC PASS; S3-16 next

Native primary; Mai Chi temporary RMS voice unchanged; no hardware. Code/assets LOCAL; documentation only.

### S3-15 native LOD runtime integration - PASS PC - 2026-10-02

- **ACTIVE RUNTIME:**software/pi/app_ui/assets/avatar/aria-avatar-idle-lod-runtime.glb SHAc6ac88d11de7c883558996766efed8ae5e80485ed576305c698f190a2e04065a,63097656bytes,290331tris. Manifest aria-avatar-new.json SHA4d0405f1d0765e8c589498f29f02c3b65d5e9b94a9da0008bcc51e774ae322c2 selects verified S3-14 output andARIA_IDLE_BREATHING48s. Previous expression GLB retained unchanged for fallback; native remains primary/default; ZeroWeight experimental untouched.33bones/25 geometry+2NORMAL-only inherited arc targets remain truthful.
- **REGRESSION:**8 idle+4 LOD targeted checks,106 avatar total and74 backend PASS;120s real continuous app WebGL+3 additional48s loops,state transitions,blink/gaze/head/mouth priority,one unchanged real Mai Chi PC utterance/end REST PASS.12 idle/voice+48 actual facial WebGL cases PASS (60total):7 visemes0/.25/.5/.75/1/0 real evaluated vertex motion,combos,reset/reload. No NaN/accumulation/camera movement(delta0). Not full project PASS.
- **PRESERVATION/EVIDENCE:**SAME source SHA1f1dcab26696fa6eef413e381454ebaf86f2aaffdbbae64fdb03356bf79eca71 unchanged sinceS3-12; master original/source geometry/voice backend/face mapping/camera constants retained. Mai Chi TEMPORARY_VOICE_ACCEPTED_FOR_NOW,RMS only,Piper fallback retained. Existing inherited UI notice aplay error1 unchanged; real test utterance starts/ends successfully. reports/S3-15/checkpoint.json,integration.json,tests.json,webgl.json,runtime_matrix.json,preservation.json,visual_review.json and genuine PNG/WebM captures. Owner visual/Pi pending.
- **CHANGED/NEXT:**manifest,new runtime output; fv_control/light_expression tests now inspect active GLB; new idle_lod_asset tests. S3-12 AvatarController/SkinnedGlbAdapter idle priority changes retained. Next S3-16 visual/framing compare retained prior runtime. No Pi benchmark/hardware. Code/assets LOCAL; doc-only reviewed sync.

## Earlier checkpoint records - retained as history

## ACTIVE CHECKPOINT - 2026-10-02 S3-14 LOD export reimport PASS; S3-15 next

Native primary; Mai Chi temporary RMS voice unchanged; no hardware. Code/assets LOCAL; documentation only.

### S3-14 LOD export/reimport - PASS PC SOURCE UNTOUCHED - 2026-10-02

- **BUILD:**models/S3-14/ARIA_AVATAR_IDLE_LOD_v1.glb,63097656bytes,SHAc6ac88d11de7c883558996766efed8ae5e80485ed576305c698f190a2e04065a; 290331tris/33 joints/27 unique facial targets(25 geometry+2 inherited NORMAL-only blinkArc repairs). Exported ONLY from SAME source+validated S3-13 RAM recipe; no .blend copy/save. Source SHA1f1dcab26696fa6eef413e381454ebaf86f2aaffdbbae64fdb03356bf79eca71 unchanged; original master untouched. ARIA_IDLE_BREATHING48s,source frame1 rebased toclock0; accepted lid-normal export repair retained.
- **VERIFY:**real Blender GLB re-import,258 evaluated0/.25/.5/.75/1/0 morph samples; REST exact,finite,real motion,48s idle loop returnsneutral. Actual image REST/mouth/F_V agent visual PASS; owner artistic approval pending. GLB audit verifies27 controls,33 joints,normalized weights,finite attributes,materials/image bytes/inverse bind matrices exact against S3-12. reports/S3-14/build.json,audit.json,reimport.json,visual_review.json,checkpoint.json and real captures/S3-14 PNGs.
- **NEXT:**S3-15 integrate verified LOD runtime then S3-16 framing/visual regression. Existing runtime/manifest still S3-10 until S3-15. Native default/Mai Chi temporary RMS voice/Piper fallback/experimental ZeroWeight preserved. No Pi benchmark/hardware. Code/assets LOCAL; reviewed doc sync only.

## Earlier checkpoint records - retained as history

## ACTIVE CHECKPOINT - 2026-10-02 S3-13 offline LOD PASS; S3-14 next

Native primary; Mai Chi temporary RMS voice unchanged; no hardware. Code/assets LOCAL; documentation only.

### S3-13 offline LOD - PASS SOURCE UNTOUCHED - 2026-10-02

- **RESULT:**290,331 triangles (274,271 main body+16,060 protected separate meshes), within200k-300k. Geometry derivative built ONLY IN RAM from SAME source; no new .blend/no source save. Recipe reports/S3-13/lod_recipe.npz SHA6bffc28f671833d60d8824cf940a60007c17096c8d6d3c45f35f48f9d5dc1072 is a derived build artifact, not source copy.
- **PRESERVATION:** source SHA1f1dcab26696fa6eef413e381454ebaf86f2aaffdbbae64fdb03356bf79eca71 unchanged. Locked all moved facial vertices/head/hair/hand/bounds/sole; 588171 protected corners and195997 protected polygons exact, protected coordinates/morph/skin weights exact, UV delta0. Custom normals explicitly restored from evaluated source; precision {'max_degrees': 0.5647836040112109, 'p95_degrees': 0.0027978107678012024, 'max_vector_delta': 0.009189549833536148} (bounded encoding tolerance, NOT binary-equal normal claim).33-bone/action/material/texture contracts retained in RAM; neutral pose bounds delta0.
- **TEST/EVIDENCE:**138 actual evaluated morph samples(23 targets x0/.25/.5/.75/1/0),finite and exact REST after cycles; real captures/S3-13 source/LOD rest and full-body plus idle/mouth/F_V. Agent visual PASS; owner artistic/Pi pending. reports/S3-13/offline_gate.json,visual_review.json,checkpoint.json. S3-12 PASS retained. Production manifest/runtime still S3-10; Mai Chi/ZeroWeight/native defaults unchanged; no hardware/Pi benchmark.
- **NEXT:**S3-14 export/reimport build artifact, then S3-15 runtime integration and S3-16 framing/regression ONLY sequential PASS gates. Code/assets local; reviewed documentation only sync.

## Earlier checkpoint records - retained as history

## ACTIVE CHECKPOINT - 2026-10-02 S3-12 native idle DEV PC PASS

Native primary/default; ZeroWeight experimental. Mai Chi TEMPORARY_VOICE_ACCEPTED_FOR_NOW, unchanged RMS mouth/Piper fallback. SAME-source idle48s PASS offline and120s WebGL. Production runtime unchanged; next S3-13 LOD then S3-14/15/16 sequential. Code/assets LOCAL; documentation only.

### S3-12 natural idle body - DEV PC PASS SAME SOURCE - 2026-10-02

- **SOURCE:** SAME models/S3-07/ARIA_AVATAR_MOUTH_CANDIDATE_v1.blend SHA1f1dcab26696fa6eef413e381454ebaf86f2aaffdbbae64fdb03356bf79eca71; no source copy/backups. Existing ARIA_IDLE_BREATHING action refined in place,48s/60fps. Nine unequal4.4-6.1s breaths with asymmetric smooth inhale/exhale,small bounded COM/spine counter-motion,offset shoulders,arm/hand settle and micro head drift; endpoints exactly neutral with flat velocity.
- **PRESERVATION:** ALL basis/topology/UV/27 facial arrays/material slots and33 bones exact; master unchanged. DEV GLB SHA14b93baf41d3653253a3a455aebdfb87a391b482fdfdfb0872474ec4dea72efb,204632816bytes; geometry/normals/skin/morph/material/texture binary data equal S3-10 output. Production manifest/runtime unchanged until planned integration gate. Same source retained for next stages.
- **RUNTIME/TEST:**120s actual WebGL idle/video,three additional48s deterministic cycles,state transitions and blink/gaze/mouth combinations PASS. Head idle smoothly yields to explicit gaze,including center hold; state body gain eases; no NaN/accumulation,snap or camera motion(delta0).8 targeted/102 avatar/74 backend/12 WebGL PASS. One unchanged real Mai Chi PC utterance/SSE/mouth->REST PASS; Piper untouched. Not full project PASS.
- **EVIDENCE/NEXT:**reports/S3-12/{checkpoint,offline,reopen,build_audit,tests,webgl,preservation,visual_review}.json and genuine captures/S3-12 PNG/video. Native primary/default,ZeroWeight experimental; Mai Chi TEMPORARY_VOICE_ACCEPTED_FOR_NOW,RMS only. Owner artistic/Pi pending. Next S3-13 offline LOD,do not save/overwrite source; only PASS permits S3-14 export/reimport then S3-15 integration and S3-16 visual. No Pi benchmark/hardware action. Code/assets LOCAL; reviewed doc sync only.

## Earlier checkpoint records - retained as history

## ACTIVE CHECKPOINT - 2026-10-02 Mai Chi PC PASS and S3-11 offline breathing PASS

Native primary/default; ZeroWeight experimental. Mai Chi temporary voice PASS PC with retained Piper fallback. S3-11 SAME-source action offline PASS; runtime unchanged. Next S3-12 SAME action. Code/config/assets LOCAL, reviewed documentation only.

### S3-11 idle breathing - OFFLINE PASS SAME SOURCE - 2026-10-02

- **SOURCE:** SAME models/S3-07/ARIA_AVATAR_MOUTH_CANDIDATE_v1.blend; SHA765d672b5ca482edfa2b63b02b7feed952fba13df2cdb5706289cb18c2cfa0f0. No blend/file copy; save backups disabled. Original master untouched. ARIA_NEUTRAL retained; active ARIA_IDLE_BREATHING action,16s/60fps,4s breathing cycles.
- **MOTION/GATE:** only Spine/Spine1/Spine2 dynamic quaternion channels,+0.50/-0.35/-0.15deg counter pitch; Spine2 bounded0.2% X/0.1% Z scale. No dynamic head/neck/hips channels. Real posed mesh movement max0.73245mm/head origin0.62464mm; hips unchanged. Reopen and five loop boundaries restore ALL33 bone matrices exactly(delta0).
- **PRESERVATION:** ALL mesh basis/topology/UV/27 real facial targets/material slots and33-bone rig data exact; no NLA/armature driver. Five true Blender captures reviewed, no apparent identity/neutral distortion. Original master/native runtime/manifest/UI/voice/ZeroWeight retained; remaining60 voice-baseline protected hashes exact.
- **BOUNDARY/NEXT:** OFFLINE PASS only, not new runtime/Pi proof. Runtime still aria-avatar-light-expressions-runtime.glb SHA2f984b72366fcd80861789b172ed23dfcb127e64aa828806c16e1b9d1fb66e9c,204571108bytes; Mai Chi temporary provider PC PASS remains current. Next S3-12 refine SAME action with bounded shoulder/arm/weight-shift phases, then planned LOD/export/app gates. No early LOD/runtime replacement. Owner visual/Pi pending.
- **EVIDENCE:** SPATIAL_OS_WORK/reports/S3-11/{inventory.json,probe.json,applied.json,checkpoint.json,report.md}; captures/S3-11/{rest,inhale_mid,inhale_peak,exhale_mid,rest_after_cycle}.png. bpy5.2.0LTS. Code/assets LOCAL; canonical documentation sync only.

## Earlier checkpoint records - retained as history

## ACTIVE CHECKPOINT - 2026-10-02 Mai Chi TEMPORARY ARIA VOICE

ZeroTTS maichi technical PASS PC; native_3d primary/default. Piper model-timed fallback retained. ZeroWeight experimental retained.74 backend/94 avatar/16 WebGL PASS,camera0. Zero uses RMS mouth amplitude, no phoneme timing claim. Code/config/assets LOCAL; reviewed documentation only. S3-11 next SAME source, no blend copy.

### ZeroTTS Mai Chi - TEMPORARY ARIA VOICE - TECHNICAL PASS PC - 2026-10-02

- **SELECTION:** tts.provider=zerotts; tts.voice=maichi; Mai Chi=TEMPORARY_ARIA_VOICE, not final. zerotts0.1.5; local model zeroweight-ai/ZeroTTS pinned c2bfbd67dc648cac455077333f7cf5c18a2e3bb4. Isolated tools/zerotts-env; model/cache/evidence on D; runtime local-files-only, no cloud/key.
- **REAL AUDIO/APP:** exact requested Vietnamese sentence synthesized as PCM16 mono48k WAV and played on PC speaker. Actual Voice/Assistant and ARIA SSE start/end -> native mouthOpen -> REST. Explicit PC worker records PortAudio output-buffer DAC schedule; Pi aplay branch retained. Actual playback cancellation cleans owned subprocess/private WAV and speech.
- **CAPABILITY:** ZeroTTS currently has no exported phoneme timestamps; AUDIO_ENVELOPE controls amplitude/jaw/mouth only, phoneme_timed=false. RMS never chooses vowels. S3-09 Piper model-timed phonemes/seven visemes remain intact when Piper fallback is used; real fallback inference/WAV/PC playback PASS. No phoneme-accurate claim for Mai Chi.
- **VERIFY:** 15 new targeted provider/event contracts within74 backend tests PASS;94 avatar regression PASS;16 WebGL cases PASS, camera delta0/no JS exceptions/NaN/stuck weights. Natural real playback/SSE plus captured-envelope terminal/state/combination probes distinguish sources. End/error/cancel/barge-in/state exit/reload REST. Barge-in microphone/acoustic validation not claimed. Agent reviewed native speaking/final REST images; earlier portrait/hidden-slot test attempts are superseded.
- **PRESERVED:**61 protected hashes exact at voice gate: SAME active blend SHA79d5d415cf64a0bfa4db77d750f55baa47dd164a38d296a39b3fc5eb8d8df991; original master SHA8cc12cc6a973e435769bef3180240eec546f7f2eed390f4514a1ab83ae7348b6; native expression GLB SHA2f984b72366fcd80861789b172ed23dfcb127e64aa828806c16e1b9d1fb66e9c,204571108bytes. No blend edit/copy, camera/geometry/frontend change or hardware action. Native_3d primary/default; ZeroWeight optional experimental retained, not activated.
- **EVIDENCE/CONFIG:** SPATIAL_OS_WORK/reports/ZEROTTS-MAICHI/{checkpoint.json,report.md,audio_smoke.json,app_voice_proof.json,real_cancel.json,webgl.json,live_app_events.json,protected_verified.json,test_runs.json}; captures/ZEROTTS-MAICHI; audio/ZEROTTS-MAICHI. External PC config reports/ZEROTTS-MAICHI/aria-maichi-pc.json selects Mai Chi plus retained Piper paths. Owned dev_server.py localhost8790 uses actual app/voice with no hardware/background services started.
- **LIMITS/NEXT:**PENDING_OWNER_VOICE/VISUAL_APPROVAL and production Pi performance/ALSA/acoustic barge-in. Not full project PASS. Code/config/builds stay LOCAL; reviewed documentation only may sync. Continue S3-11 idle breathing/spine/chest on SAME source, no .blend copy. S3-12 follows its gate; no LOD task now. Last reported Codex remaining62%, above20% stop threshold.

## Earlier checkpoint records - retained as history

## ACTIVE CHECKPOINT - 2026-10-02 ZeroWeight OPTIONAL SECOND avatar renderer gate

Native avatar retained; current default native_3d. ZeroWeight QYbF5iSbLYI0wdBTIIEG optional DEV renderer PASS PC. STOP renderer integration; no ZeroWeight audio work or native replacement. Native S3-09/S3-10 PC proofs retained; owner visual/production Pi pending. Code/SDK/GLBs local; this publication contains reviewed documentation only.

### ZeroWeight optional SECOND avatar — renderer gate PASS PC — 2026-10-02

- **STATUS/DEFAULT:** PASS_OPTIONAL_SECOND_AVATAR_RENDERER_PC. Native avatar retained and current default native_3d; ZeroWeight optional second provider only. Avatar ID QYbF5iSbLYI0wdBTIIEG. No default change or provider persistence; DEV Native 3D / ZeroWeight switch only. Stop at renderer integration gate.
- **REAL BUNDLE/SDK:** server-only environment credential; real proxy/upstream HTTP200, nonempty opaque object payload. @zeroweight/renderer0.2.46 vendored unmodified/lazy, module SHA03f793c4cae679a5bdc62d39e623c39be23a8b55dfc157bd4bb590a8a79bf083. READY/dimensions1080x1920 and genuine canvas rendering confirmed. Opt-in CSP allows embedded WASM/exact CDN; disabled/native policy unchanged.
- **REAL ACTIONS:** listening,speaking,wave_hand,think,speaking_excited. IDLE/STANDBY/SLEEP fallback listening (idle/sleep unavailable); LISTENING->listening, SPEAKING->speaking, THINKING->think. No fake action/capability or audio-sync claim. Piper/native viseme pipeline unchanged; ZeroWeight TTS/ActionQueue/VAD NOT opened.
- **VERIFY:**17 targeted proxy tests included in59 backend regression PASS;94 native avatar +11 provider lifecycle tests PASS;101 post-change native WebGL +28 ZeroWeight actual-app runtime cases PASS. Repeated switch/destroy/reinit, rapid cancel, simulated401 recovery, reload default/native cache preservation PASS. Camera delta0/no JS exceptions; 64 native/source/GLB/manifest/layout/voice hashes exact; actual key absent from repo/evidence/browser requests. Full project suite not run.
- **EVIDENCE:** SPATIAL_OS_WORK/reports/ZEROWEIGHT-INTEGRATION/{checkpoint.json,report.md,final_verification_renderer.json,bundle_probe.json,renderer_package.json,renderer_smoke.json,runtime_proof.json,renderer_review.diff,test_runs.json}; native_post_integration/webgl_runtime.json. Real captures under captures/ZEROWEIGHT-INTEGRATION. Earlier missing-key/schema/CSP attempts retained as history, superseded by PASS. Agent reviewed images; PENDING_OWNER_VISUAL_APPROVAL/production Pi performance.
- **PRESERVATION/NEXT:** same active native S3-07 blend SHA79d5d415cf64a0bfa4db77d750f55baa47dd164a38d296a39b3fc5eb8d8df991; native expression runtime SHA2f984b72366fcd80861789b172ed23dfcb127e64aa828806c16e1b9d1fb66e9c,204571108bytes. No blend/source copy, geometry/master/runtime overwrite or hardware action. Test on owned localhost8789/?dev=1 on Tun; config enabled in memory only. Code/SDK/GLBs LOCAL; reviewed handoff sync alone permitted. STOP at requested renderer gate; owner visual/Pi next, native default retained.

## Earlier checkpoint records - retained as history

## ACTIVE CHECKPOINT - 2026-10-02 S3-09 and S3-10 technical PC completion

S3-09 native Piper model timing is complete on PC; S3-10 real light expression runtime is now PASS PC on the SAME source. Code/build remain local. Owner visual and production Pi validation pending. Documentation-only sync; next roadmap S3-11 not opened in this request.

### S3-10 light facial expressions - TECHNICAL PASS PC - 2026-10-02

- **STATUS:** PASS_PC_LIGHT_FACIAL_EXPRESSIONS. Six semantic states listening/thinking/speaking/concerned/alert/sleep now reach five real native smile/frown/browUp/browDown/browConcern morphs. Soft bounded interpolation, antagonist sums<=1; idle variation cannot leak into a requested state/neutral. Sleep retains inherited blink eyelids. No eye-wide/squint capability claim.
- **SAME SOURCE:** models/S3-07/ARIA_AVATAR_MOUTH_CANDIDATE_v1.blend edited in place; SHA256 79d5d415cf64a0bfa4db77d750f55baa47dd164a38d296a39b3fc5eb8d8df991, 162400292 bytes. Only five new shape keys; original Basis/topology/UV/material slots/old mouth-viseme-eye keys and all33 bones exact. No source copy/backups, no original master or oral geometry rewrite. Master SHA8cc12cc6a973e435769bef3180240eec546f7f2eed390f4514a1ab83ae7348b6 unchanged.
- **BUILD/RUNTIME:** models/S3-10/ARIA_AVATAR_LIGHT_EXPRESSIONS_v1.glb -> app_ui/assets/avatar/aria-avatar-light-expressions-runtime.glb, SHA256 2f984b72366fcd80861789b172ed23dfcb127e64aa828806c16e1b9d1fb66e9c,204571108 bytes,27 unique targets/33 joints. Manifest now selects this output; old runtimes retained. Texture bytes/material definitions and accepted camera/frame constants exact. No LOD work.
- **VERIFY:** 56 offline expression/viseme pairs +72 FV/U intermediate cases PASS after bounded refinements to NEW expression keys only. 78 export/reimport cycles, neutral exact. 12 expression targeted +82 inherited avatar tests=94 PASS;39 backend regression PASS. 21 expression WebGL +101 S3-08 regression +24 real-Piper timing cases PASS; no JS exception/NaN/stuck speech, camera delta0. Real WAV clock drift max38.951ms; seven phoneme-driven targets with RMS intensity retained. Full project suite not run.
- **EVIDENCE:** SPATIAL_OS_WORK/reports/S3-10/{checkpoint.json,final_report.json,report.md,inventory.json,applied.json,offline_gate.json,export_reimport.json,integration.json,review.diff,expression_targeted.log,avatar_regression.log,backend_regression.log,webgl_expression.json,visual_review.json,final_verification.json}; s308_regression/webgl_runtime.json, s309_regression/webgl_timing.json; captures/S3-10 genuine source/reimport/WebGL images, agent reviewed. S3-09 discovery/audio/timing evidence retained.
- **LIMITS/NEXT:** PENDING_OWNER_VISUAL_APPROVAL and production Pi live Piper/model/aplay/ALSA onset/drift/FPS. Model-predicted alignment is technically sourced, not human acoustic accuracy certification. Existing low-poly facial/lid appearance and hair brow occlusion remain. Code/GLB stay LOCAL; reviewed canonical documentation only may sync. S3-11 is next roadmap code but NOT opened in this S3-09/S3-10 request. Preserve SAME source and no copies when continuing; hardware HOLD unchanged.

## Earlier checkpoint records - retained as history

## ACTIVE CHECKPOINT — 2026-10-02 S3-09 technical PC completion

Current local implementation/evidence stays on D. This newest checkpoint supersedes earlier amplitude-only completion; next S3-10 on same source. Documentation-only sync; app/GLB and hardware remain local.

### S3-09 real Piper phoneme/model timing - TECHNICAL PASS PC - 2026-10-02

- **STATUS:** PASS_PC_PIPER_MODEL_TIMED_VISEMES. Replaces the amplitude-only completion gate. Genuine phoneme sequence and per-ID sample durations come from the SAME Piper inference creating the WAV. REST/A/E/I/O/U/M_B_P/F_V are selected by phones; RMS controls intensity only. No random/equal-time/RMS-derived vowel schedule or human acoustic-accuracy claim.
- **PROVIDER:** PC proof piper-tts1.8.0, bundled eSpeak-ng vi, pinned vi_VN-vivos-x_low ONNX SHA6ab13374eb0862021a545befe7727aef59e16117f1c075aa9e0362237ecc98ae, rate16000/hop256. Memory-only alignment output /Ceil_output_0 supplies exact sample counts. Unknown Vietnamese tone tokens skipped by model are recorded with zero samples; strict ID matching repairs upstream convenience-grouping failure. Stress prefixes map following phone, suffix length maps preceding; no timing rescale.
- **IMPLEMENTATION:** optional ARIA_PIPER_PYTHON uses native Python API through the existing cancellable Voice/Piper/WAV/aplay pipeline. CLI amplitude fallback remains explicitly labelled. Model timeline validated against WAV and forwarded through existing tts:start/snapshot. Soft bounded crossfade; no double jaw. Aligned ALSA start requires owned RUNNING PCM hw_ptr/native rate and reports uncertainty; missing clock stops playback and withholds timeline. Production Pi setup remains unverified.
- **REAL PROOF:** real_full.wav, 16000Hz monoPCM16, 177920 samples/11120ms/355884 bytes, SHAa6fdeb925b6c6e7e825de417401c85577c7a387a2c66da8f05262f4d9b9cb7f2. Actual PC browser played this WAV; model timeline used advancing audio-playhead t0_ms. Max measured clock drift36.964ms. Seven actual native targets observed; natural end and every end/error/cancel/barge-in/state-exit/rapid/consecutive/reload path REST.
- **VERIFY:** 82 avatar tests (68 inherited+14 timing, real trace included), 39 backend tests (11 inherited+28 timing/clock/event contracts), 24 genuine-WAV WebGL cases, 101 fresh S3-08 WebGL regression cases, 10 syntax checks PASS. Camera delta0; no JS exception/NaN. Eight protected source/build/runtime hashes and unchanged RMS implementation/manifest frame PASS. Full project suite not run.
- **SAME SOURCE/BUILD:** models/S3-07/ARIA_AVATAR_MOUTH_CANDIDATE_v1.blend SHAa4a1a7188028b22ff6f5bbb1927aacb78caeb3a0800212efce6ba4977073ad7f. No source copy/save or geometry change in S3-09. Existing full GLB candidate/runtime SHA0fa65c26ca5d62e27de6a709209e1cda32498dbae13019fbc353fc577416bce5,170864684 bytes,22 targets/33 bones. Master SHA8cc12cc6a973e435769bef3180240eec546f7f2eed390f4514a1ab83ae7348b6 untouched.
- **EVIDENCE:** SPATIAL_OS_WORK/reports/S3-09/phoneme_timing_discovery.md; phoneme/{webgl_timing.json,wav_metadata.json,Vietnamese_phoneme_mapping.tsv,mapping_revision.json,test_runs.json,backend_final.log,avatar_final.log,final_verification.json,review.diff,s308_regression/webgl_runtime.json}; audio/S3-09/phoneme/{real_full.wav,real_full_alignment.json,payload.json,text.txt}; captures/S3-09/phoneme real rendered images, reviewed by agent.
- **LIMITS/SYNC:** PC technical gate only. PENDING_OWNER_VISUAL_APPROVAL; production Pi Piper version/model, actual ALSA onset/drift/DAC latency and FPS pending. Predicted model alignment is technically sourced, not human forced alignment. Existing low-poly lip faceting retained. Code/GLB stay LOCAL; only reviewed canonical handoff may be synced. No hardware action, source-copy or LOD work.
- **NEXT:** automatically start S3-10 LIGHT FACIAL EXPRESSIONS on SAME active blend; no copy. Preserve existing mouth/visemes/teeth/blink/gaze/head/camera and all33 bones. Re-read S3-10 checkpoint if present before edits.

## Earlier checkpoint records - retained as history

## ACTIVE CHECKPOINT — 2026-10-01: S3-08 full minimum + S3-09 PC real-audio baseline

Current working repository/evidence: D:/UserData/ARIA/repo and D:/UserData/ARIA/SPATIAL_OS_WORK. This reviewed checkpoint records local PC implementation. App code/build outputs remain local; this documentation-only sync does not publish the untracked app foundation or deploy Pi/hardware. All motor/encoder/driver/ESP work remains paused. PCB state stays in docs/ARIA-PCB-PRO-MAX-CANONICAL.md.

### S3-09 real audio to native mouth - PASS PC amplitude baseline - 2026-10-01

- **STATUS:** PASS_PC_REAL_PIPER_AUDIO_AMPLITUDE_BASELINE. Genuine Piper WAV/RMS drives actual mouthOpen geometry while SPEAKING. No audio gives REST. Seven real native visemes remain available; bounded explicit timed labels map to them. Current producer publishes RMS only: phonemeAccurate=false, no automatic phoneme/viseme selection claim.
- **SOURCE/BUILD:** SAME models/S3-07/ARIA_AVATAR_MOUTH_CANDIDATE_v1.blend, SHA256 a4a1a7188028b22ff6f5bbb1927aacb78caeb3a0800212efce6ba4977073ad7f. No S3-09 source save/copy or GLB rebuild. models/S3-08/ARIA_AVATAR_VISEME_FULL_v1.glb and assets/avatar/aria-avatar-viseme-full-runtime.glb remain SHA256 0fa65c26ca5d62e27de6a709209e1cda32498dbae13019fbc353fc577416bce5, 170864684 bytes, 22 targets/33 joints. Manifest points to full runtime; camera constants unchanged.
- **IMPLEMENTATION:** existing LipSyncController/AvatarController/native adapter/AppStore hooks extended, not rewritten. RMS controls amplitude only; explicit visemes use full shapes without doubling jaw opening. Matching end/error/cancel/barge-in or leaving SPEAKING clears real weights immediately; EOF also bounds progress. Delayed old end/start/progress cannot close or resurrect a newer/finished turn within bounded id history. Reload/unload clear native mouth; manual S3-08 controls preserved.
- **REAL AUDIO:** local Piper 1.8.0, pinned official vi_VN-vivos-x_low proof voice (not production Pi voice configuration), 16000 Hz mono PCM16 WAV, 7504 ms/240172 bytes; SHA256 2c50b2c965c2fdf331e9762fe7afa4550a22fe2599813d3ecc4522ee5ceb563d. RMS extracted by existing unmodified Voice.envelope at 20 ms, 376 frames. PC browser actually played that WAV; existing AppStore/UI TTS hooks consumed the actual RMS/t0_ms. No sine or synthesized envelope mouth proof.
- **VERIFY:** 13 new targeted +55 related avatar tests =68 PASS; 11 mock backend voice/envelope/start/end/barge-in contract tests PASS; five JS syntax checks PASS. Actual-app WebGL real-audio matrix 18 cases PASS: no audio, full playback/natural end, four terminal events, IDLE/LISTENING exits, rapid/consecutive turns/stale events, blink/gaze L/R/U/D/center/head, reload. All terminal/state/reset weights REST; no JS exception/NaN, production camera delta0. Separate post-change S3-08 101-case actual-model regression PASS.
- **PRESERVATION:** eight protected source/build/runtime hashes PASS including original master SHA8cc12cc6a973e435769bef3180240eec546f7f2eed390f4514a1ab83ae7348b6 and S3-06 source. S3-09 changed no model geometry/material/texture/rig; S3-08 visual geometry gates remain valid. PCB/firmware/motor/encoder/driver/ESP untouched.
- **EVIDENCE:** D:/UserData/ARIA/SPATIAL_OS_WORK/reports/S3-09/{checkpoint.json,final_report.json,report.md,real_audio.json,webgl_real_audio.json,avatar_regression_final.log,backend_voice_contract_tests.log,syntax_checks.json,final_verification.json,review.diff}; s308_regression/webgl_runtime.json. Genuine WAV/payload under audio/S3-09; real images under captures/S3-09 and s308_regression. Earlier harness/UTF-8 failures retained as historical attempts, superseded by verified PASS outputs.
- **LIMITS:** technical PC baseline only. Piper phoneme timing is not published; explicit-timing tests are input-contract proof, not phoneme-accurate speech. PC developer event relay/browser playback is not production Pi transport/aplay. SSH Pi access attempts failed; no deployment/service/hardware action. Pi/FPS, owner artistic/phonetic acceptance and full-project suite remain PENDING. Original low-poly lip faceting remains visible close-up.
- **SYNC/NEXT:** reviewed S3-08/S3-09 handoff sections may be published alone; shared untracked avatar foundation and large runtime remain LOCAL, without broad staging/push or LFS/LOD scope expansion. Next verification: owner visual/phonetic review and accessible Pi live Piper/aplay/state proof; phoneme-driven selection requires a real timing source. No further source copy or new facial/LOD task opened in this block.

### S3-08 full minimum set including F/V - PASS PC - 2026-10-01

- **STATUS:** PASS_FULL_MINIMUM_REAL_VISEMES_PC: REST/A/E/I/O/U/M_B_P/F_V are real controls. Four beveled closed solid incisors and internal gum added inside current oral cavity; lower lip rolls toward incisors. No plane/sprite/texture teeth or capability-only flag.
- **SOURCE:** same models/S3-07/ARIA_AVATAR_MOUTH_CANDIDATE_v1.blend, edited in place; SHA256 a4a1a7188028b22ff6f5bbb1927aacb78caeb3a0800212efce6ba4977073ad7f. No new source .blend/.blend1; original master unchanged SHA8cc12cc6... . Previous subset source SHA66713590... is historical.
- **BUILD/RUNTIME:** models/S3-08/ARIA_AVATAR_VISEME_FULL_v1.glb -> assets/avatar/aria-avatar-viseme-full-runtime.glb; SHA256 0fa65c26ca5d62e27de6a709209e1cda32498dbae13019fbc353fc577416bce5; 170864684 bytes, 22 unique targets, 33 joints. Old build outputs retained. Manifest frame constants unchanged; no LOD work.
- **VERIFY:** 42 seven-target cycle samples and 131 dense F/V/transition samples PASS; no new oral/dental intersection or affected exterior inversion. REST pixels equal previous checkpoint and after cycle; source old controls max delta 0.18 micrometer, original UV/material/lids/rest bones exact. Reimport old neutral maximum delta 0.0103 micrometer; original texture bytes/material definitions exact. Six blink/gaze/head combinations preserved. Hidden inherited closed-rest contact pairs are explicitly documented.
- **APP/TESTS:** actual F_V mapping/capability; 7 FV targeted + 48 full related avatar tests =55 PASS, 101 actual-app WebGL cases PASS, camera delta0, no exceptions/NaN, reload correct. Three stale assertions updated to accepted LISTENING neutral and current 33-bone asset priority; no behavior was reverted to old asset.
- **EVIDENCE:** reports/S3-08/fv/final_report.json, offline_gate.json, transition_gate.json, preservation.json, export_reimport.json, avatar_regression_verified.log, webgl_runtime.json; real source/reimport/WebGL images captures/S3-08/fv. Agent PC visual reviewed; owner artistic/phonetic and Pi/FPS pending; close-up low-poly faceting remains. No TTS/phoneme-accurate claim in S3-08.
- **SYNC/NEXT:** app code/assets remain local because shared untracked foundation is absent on origin and 170MB GLB has no LFS filter. No broad stage or dirty-tree publication. Automatically start S3-09 using current runtime/source; amplitude versus phoneme timing must be distinguished.

## Earlier handoff records — retained; hardware hold and verification boundaries still apply

**Status: CURRENT/CANONICAL · Migration + local live-source consolidation: 2026-09-12**

## ACTIVE CHECKPOINT — 2026-09-13: Pi sensors/audio; all motor work PAUSED

### Ứng dụng tạm thời dùng khuôn mặt đang có trong app — 2026-09-14

Để tạm thời quay về mặt chuẩn đang chạy trong UI, đã chỉnh `software/pi/app_ui/index.html` mặc định `data-avatar="three"` và buộc khởi tạo trong `software/pi/app_ui/app.js` về mode `three` (trừ khi user đã chọn `animated`). Hạn chế: chế độ `portrait` vẫn khả dụng khi người dùng chọn lại trong Cài đặt; không có thay đổi firmware, cảm biến hoặc cấu hình motor/hardware.

### Accessible-message synchronization — 2026-09-13, avatar rejection and incomplete likeness

Archived 8 user/final-assistant text items from [Tạo avatar 3D khuôn mặt ARIA](conversations/2026-09-13-01a09aae-avatar.md), covering all four API-returned turns, and 4 new items from [Tạo mô hình 3D](conversations/2026-09-13-6aa68f57-avatar-followup.md), deduplicated against the published checkpoint. Both sources were idle; the latest source turn ended, but its requested likeness goal remains INCOMPLETE. Source work was already published through `e1f8aad`; this synchronization only adds reviewed documentation, without rerunning Blender or modifying preserved experiments.

CURRENT: owner requests an actual animated 3D face, rejects R6, and asks to continue direct Blender modeling until it resembles the reference. The source final response explicitly states that this requirement has not been met. R4 remains the previously selected baseline; R7-R26 are unapproved appearance studies. Source-reported render/fit results and R6 export checks must not be presented as owner acceptance, animation readiness of R26, or Pi verification. Next action remains resolving hair/temple boundaries and validating three-view likeness in the source modeling task before facial animation/integration.

Coverage is accessible text only; image pixels, linked deliverables, older backlog and unavailable account/cloud history remain outside this run. No model acquisition, code edits, hardware, flash or Pi service action; MOTOR/ENCODER/DRIVER HOLD preserved. Other listed ARIA sources had no newer activity relative to the prior run.
### Original generated character sheet recovered — 2026-09-13

Owner reports excessive blur and directs the agent to find the original in chat. VERIFIED: the native ChatGPT page for conversation 6aa68f57-f678-83ee-a054-4ade51c4878f contains the generated image titled Bảng Trình Diễn Nhân Vật 3D Chuyên Nghiệp, omitted by read_thread's attachment export. Downloaded through its Save control and verified PNG 1536 x 1024, 2,344,138 bytes; preserved at assets/characters/aria-custom/reference-fit-inputs/original-generated-character-sheet.png. Includes front/oblique/profile/back and eye/lip/hair detail panels. Earlier modeling used the 773 x 396 screenshot and missed this generated sheet. This is a distinct generated reference, not a lossless higher-resolution copy of that screenshot. Printed wireframe, 4K texture and mesh-count labels are illustrative content, not real model data or verified assets. No Blender texture update has yet been made from this newly recovered image. Next appearance work must inspect this original and its detail panels rather than claim only the small screenshot is available.

### Reference likeness iteration R8-R26 — 2026-09-13, INCOMPLETE

Owner explicitly requests continued Blender work until the face resembles the supplied three views. R8-R26 are preserved appearance experiments, not a finished or selected avatar. Latest files are under assets/characters/aria-custom/r26-review; preceding numbered directories are historical iterations. R4 launcher remains unchanged. No hardware/runtime/pipeline change.

Verified: local Blender saves and multiview renders through R17; R16/R17 oblique/profile inspection exposed photo stretching at the temple, incomplete hair coverage and an inaccurate lower-face silhouette. R18 inspection still showed hard skin-projection borders. R19-R20 rebuilt continuous hair coverage; R21 corrected lip/chin depth using sampled reference profile silhouette and smoothed lateral surfaces. R22 per-pixel hair masking alone did not resolve visible skin borders. A clay diagnostic verified a continuous, smooth head surface; isolated textured-head rendering traced the remaining jagged appearance to skin projection boundaries. R23-R25 extended clean skin-edge colors and rebuilt normalized per-pixel hair projection; inspected renders still show conspicuous temporal/ear seams and view-dependent artifacts. R26 restricts photographic detail to the central face with a smooth side blend; front, three-quarter and near-profile renders visually inspected. Visible hairline blocks, exposed ear/temple patches and profile mismatch remain; R26 does NOT meet the requested likeness. Appearance remains below the owner requested standard. Repeated projection adjustments have not established a satisfactory three-view likeness; do not treat a frontal resemblance as completion. Actual head, eyes and curved hair meshes exist. Appearance is heavily dependent on low-resolution source-photo projection, not a finished reconstructed texture or strand groom. Likeness remains INCOMPLETE; do not call these animation-ready. No rig/teeth/blendshape/export validation for these appearance studies; R6 export checks do not transfer.

Inputs and provenance: assets/characters/aria-custom/reference-fit-inputs/README.md and saved JSON/NPY inputs. Local MediaPipe landmarks guide 142 frontal constraints; this 2D fit residual is NOT 3D accuracy or likeness evidence. Builders fit_head_r8.py and refine_r9.py through refine_r26.py retain the actual mathematical edits and local dependencies. Original three-view reference is packed in the Blender files. Next: resolve hair/temple material boundaries and assess real three-view likeness rather than continuing blind projection patches, then reintroduce facial animation only after appearance is satisfactory. Usage at 4% remaining prompted this recovery checkpoint; task is not declared complete.

### R6 rejected; direct Blender head study R7 — 2026-09-13

Owner explicitly rejects R6 appearance ("xấu không tả nổi") and asks to create directly in Blender. R6 is REJECTED/HISTORICAL, not a viable selected avatar or a basis for further cosmetic patching. Preserved all existing files. Created `assets/characters/aria-custom/r7-head-study/aria-head-r7.blend` directly from R4, with four editable proportion layers for jaw/chin, nose, eyelids and lips, cropped head/bust and the original three-view reference packed. No hair or facial animation work in R7; no pipeline or hardware change. R4 remains the previously selected baseline; R7 is unapproved.

VERIFIED: Blender saved R7 and rendered front/three-quarter/profile. Front and three-quarter visually inspected; reference likeness is still NOT VERIFIED and the result remains a generic proportion study. The adjustment layers are authored mathematical deformations, not a claimed hand-sculpt or automated reconstruction. Brow/lid curves were moved to follow the fully applied study and are not driven by individual layer weights. Source: `tools/avatar/build_head_r7.py`. A separate deliverable copy is opened in native Blender for the owner to inspect alongside the reference. Next: visual review of face proportions before further detail; do not present this as a finished likeness. Usage check reported 17% remaining and the owner was informed; checkpoint kept bounded.

### R6 facial animation candidate — 2026-09-13

Continued owner request from "Tạo mô hình 3D" after reading current main and the existing R4 selection. Recovered and visually inspected the actual attached three-view reference. Created a separate R4-derived candidate in `assets/characters/aria-custom/r6-candidate/`: editable packed Blender file, GLB, FBX, five rendered views/expression samples, source reference, licenses, build report and export validation. Builders: `tools/avatar/build_face_r6.py` and `validate_face_r6.py`. R4 and its launcher remain the selected baseline; R6 is NOT an owner-approved replacement.

VERIFIED on local PC: Blender 5.2/MPFB 2.0.17 build and save; head/bust quad mesh with one smoothing level baked; separate eyes, teeth_base, tongue01, long-hair mesh blockout, brows/lid details and a MakeHuman rig containing head/neck bones. Loaded 52 ARKit-style CC0 faceunits from makehumancommunity/extra-targets commit `7eaba3453134385bb5ea9811ef0b33b85b4b556d`. Both GLB and FBX were imported into fresh scenes and retained all 52 named head keys and 163 bones. All 52 controls have nonzero displacement somewhere on the avatar; tongueOut affects the tongue, not the cropped skin mesh. GLB evaluated geometry changes across sample animation frames after import. GLB is about 46.2 MB and FBX about 28.0 MB; these are PC review artifacts, not optimized Pi assets.

PARTIALLY VERIFIED: front/three-quarter/profile, blink and jaw-open renders visually inspected. Fixed submerged brows via baked smoothing, jagged lip coloration via vertex colors and moved the stock dental mesh back to reduce exposed gums. Teeth are now recessed and dental placement still needs refinement. A four-second animation exercises blink, jaw opening, smile, gaze and head rotation; this is not audio lip-sync. The presence of morphs and imported actions does not certify every expression or combination. Brow/lash transfer uses approximate nearby-surface correspondences.

NOT VERIFIED / OPEN: reference likeness remains inadequate for a final avatar; hair is visibly a coarse blockout, skin lacks detailed texture, mouth/eyelids need corrective shaping, and full-range combinations/contact are not exhaustively checked. Existing source preview can load GLB animations, but no live ARKit controller contract or Pi performance was established. No UI/pipeline, service, hardware or main-avatar replacement occurred. No paid tool/API was used.

Next visual work: improve hair silhouette/parting and face likeness against the packed three-view reference, then inspect each morph and combinations (especially lids, gums/teeth and lips), reduce mesh/bone/draw-call cost, and benchmark on Pi before integration. General technical NEXT STEP ORDER and hardware HOLD remain unchanged.

### Accessible-message synchronization — 2026-09-13, custom head and Tripo

Archived 24 new user/final-assistant texts from [Tiếp quản và kiểm tra ARIA](conversations/2026-09-13-01a0916f-custom-head.md) after the prior published checkpoint, plus 11 text items from all six API-returned turns of [Tạo mô hình 3D](conversations/2026-09-13-6aa68f57-model.md). Source modeling work was completed/idle and already published through `82f9216c12e1f80b3791e7752f79b82e3ea64e88`; synchronization adds documentation only and does not rerun Blender or source validation. Historical backlog, omitted image pixels and inaccessible cloud files remain outside coverage.

**Current decision:** preserve R4 as the selected local custom-head baseline after the owner rejects R5 as too dark. Next local modeling step remains hair; exact reference likeness, expressions/rig and Pi runtime remain unverified. The new ChatGPT exchange explores Tripo image-to-3D and a free downloadable alternative; this does not supersede R4 or establish an accepted replacement. Owner reports an apparent paid-export restriction and asks to try recreating the reference. Source-assistant statements about the page/model and export availability are secondary interpretations, not independently verified product/account or mesh evidence. No downloadable model, license, rig or ARIA integration result was inspected; the latest request has no assistant completion returned.

**Next evidence:** in the originating modeling task, establish whether an actual candidate file can be exported with usable licensing, then inspect likeness, geometry and facial animation capability before any replacement decision. Do not interpret archived requests as synchronization execution authority. No purchase, model acquisition, code, hardware, flash or Pi service action occurred here; MOTOR/ENCODER/DRIVER HOLD remains unchanged.

### Current selection restored to R4 — 2026-09-13

Owner finds R5 too dark and requests the first brow correction; restored selection to R4 (first correction after the supplied brow close-up). VERIFIED: existing R4 file retained unchanged and launcher points to it. R5 preserved as historical comparison, no model regenerated or deleted. Static fitting remains PARTIALLY VERIFIED; animation and Pi deployment NOT VERIFIED. Current modeling baseline is `aria-head-r4.blend`; next step is hair. Hardware holds unchanged.

### Historical custom head R5 — stronger brow density, 2026-09-13

Owner rejects R4 brows as still thin/pale. Created separate `aria-head-r5.blend`: wider dark-brown brows, 2,200 tapered strands plus surface-fitted pigmented underlayers to remove bright gaps. Face/eye proportions preserved. VERIFIED: Blender saved and rendered three views; front visually inspected for clearly increased width and darkness. PARTIALLY VERIFIED: static fitting. NOT VERIFIED: owner acceptance, expression rig and Pi runtime. Builder `tools/avatar/refine_brows_r5.py`; launcher opens R5. R4 preserved. Next: review brow shape/density before hair. Hardware holds unchanged.

### Custom head R4 — fuller brows, 2026-09-13

Owner finds R3 brows too thin against supplied close-up. Preserved R3 and created `aria-head-r4.blend` with 1,400 tapered surface-fitted strands, a wider brow body and tapered tail; existing face targets, eyes and eyelid details unchanged. VERIFIED: Blender saved R4 and rendered three views; front inspected for density and silhouette. PARTIALLY VERIFIED: static surface fit; reference likeness remains subject to review. NOT VERIFIED: expressions/rigging and Pi deployment. Builder `tools/avatar/refine_brows_r4.py` recreates R4 from R3; preserve later manual edits before rerunning. Launcher now opens R4. Next: long dark hair silhouette after this brow correction. Hardware HOLD unchanged.

### Custom head R3 — brows and lid details, 2026-09-13

Owner accepts the R2 appearance as a modeling direction ("đẹp rồi tiếp theo"); this is not approval of exact reference likeness or completed animation. Created `assets/characters/aria-custom/aria-head-r3.blend` separately, retaining R2 geometry and all shape-target values. Added 270 tapered surface-fitted brown brow strands, four subtle eyelid-margin curves and 38 upper eyelashes. VERIFIED: Blender build/save, three renders (front/three-quarter/profile) generated and visually inspected; counts/settings in `head-r3-report.json`. PARTIALLY VERIFIED: static surface fitting only, not eyelid contact during expressions. NOT VERIFIED/pending: hair, skin textures, clothing, gaze/blink and facial rig, final reference likeness and Pi performance. Builder `tools/avatar/refine_head_r3.py` recreates R3 from R2; save future manual changes separately before rerunning. Launcher opens R3; browser still shows the old rejected avatar. Next modeling step: build the long dark hair silhouette and layered locks against the approved reference, preserving accepted face proportions. Hardware holds unchanged.

### Custom head R2 — static eyes and profile, 2026-09-13

Created `assets/characters/aria-custom/aria-head-r2.blend` from preserved R1. Replaced temporary clay eye spheres with ivory sclera and curved brown iris/pupil geometry/materials at MPFB eye landmarks; applied five editable bilateral eyelid-height/nose-tip/upper-lip targets. VERIFIED: Blender build/save and front/three-quarter/profile renders; front and oblique render inspected. PARTIALLY VERIFIED: static eye fitting only, not motion/contact across expressions. NOT VERIFIED/pending: exact concept likeness, tearline, brows/lashes, hair, skin detail, gaze/blink rig, expressions and Pi deployment. Builder/settings retained in refine_head_r2.py/head-r2-report.json; launcher opens R2. Browser remains old rejected avatar, not this new Blender work. Next modeling step: refine eyelid margins/tearline and brows, then reassess face likeness before hair and animation. Hardware holds unchanged.

### Custom head proportion study R1 — 2026-09-13

Completed the next modeling pass in `assets/characters/aria-custom/aria-head-blockout-r1.blend`, preserving the original MPFB base. Thirteen editable MPFB shape targets adjust the oval silhouette, jaw/chin, nose width, lip volume/cupid bow/corners and bilateral eye scale. This is a parametric proportion study, not a hand-sculpted or approved likeness. Added temporary clay eye spheres at MPFB eye landmarks and non-destructive subdivision for review. VERIFIED: Blender build/save and clay renders (before front, R1 front/three-quarter/profile), inspected front and profile; source values are in head-r1-report.json. PARTIALLY VERIFIED: proportion direction only, not measured likeness; temporary eye fitting still needs refinement. NOT VERIFIED: exact resemblance, skin, hair, clothing, facial rig/expressions and Pi performance. Launcher now opens R1; browser preview still shows the rejected earlier model and is not evidence for this new Blender work. Next modeling task: refine eyelids/eye fitting and nose/lip profile against reference, then recheck silhouette before hair and rigging. Hardware holds unchanged.

### Modeling preparation — MPFB base, 2026-09-13

VERIFIED: installed MPFB 2.0.17 from its official tagged source (80919fa4682335c41847f761a4d79dcad4124732) as a local Blender extension in the isolated `D:/UserData/ARIA/tools/blender-profile`. Blender 5.2 registered the extension and created/saved `assets/characters/aria-custom/aria-human-base.blend`: adult-female base (19,158 vertices including helpers), packed concept references. Original reference workspace and rejected anime draft preserved. Launcher `tools/avatar/Open-ARIA-Blender.cmd` selects the correct D-drive profile. Code/source downloads, extension preferences and cache stay on D; default user profile not replaced. Base-asset CC0 license and setup report retained with artifact. PARTIALLY VERIFIED: preparation in background Blender, not a native UI/interactive sculpt test. NOT VERIFIED/pending: separate eyeballs, hair, clothing, custom likeness sculpt, rig, expressions and Pi deployment. Next action: fit the new head's proportions/silhouette to the chosen portrait before detail and animation. A base mesh is not completion of the exact-likeness requirement.

### Blender setup verified — 2026-09-13

Owner asks to use/install Blender locally for custom modeling. VERIFIED: existing `C:/Program Files/Blender Foundation/Blender 5.2/blender.exe` reports Blender 5.2.0 LTS and successfully runs the reference-workspace builder; no duplicate installation/download was needed. Created `assets/characters/aria-custom/aria-custom-sculpt.blend` with both reference images packed, a reference viewport and empty custom-sculpt collection using `tools/avatar/prepare_sculpt_workspace.py`. This file is a REFERENCE WORKSPACE, not a new character mesh. No native-window visibility verification, MPFB installation, custom sculpt/rig, likeness acceptance or Pi deployment is claimed. Project outputs remain on D; rejected draft remains preserved. Next step: create a suitable human base and custom head sculpt in this new workspace, checking actual silhouette against the concept before animation.

### Custom character direction — owner agreement, 2026-09-13

Owner agrees to a custom character based on concept 1 after rejecting the stock draft and marketplace examples. Generated `docs/design/aria-face-concepts/01-turnaround-reference.png` with built-in image_gen using approved concept 1 as identity/style reference. VERIFIED: saved three-view raster concept sheet (front, oblique, near-profile), visually inspected. PARTIALLY VERIFIED: identity resemblance and cross-view consistency are qualitative; generated views are not calibrated orthographic geometry and the side view is not an exact 90-degree profile. NOT VERIFIED: new custom mesh, topology, rig, expressions, Pi runtime or achievement of this visual quality in 3D. No new model was created in this checkpoint; rejected stock draft remains preserved, not approved. Next custom-model step is sculpting a new head against the approved portrait plus these approximate views, checking silhouette before rigging. No paid acquisition/upload or hardware actions authorized by this design decision.

### Owner rejects current 3D draft — 2026-09-13 10:55 UTC

CURRENT visual checkpoint supersedes the earlier review/refinement next action: owner explicitly rejects the refined draft ("xấu") and asks where to find a downloadable 3D character. Concept 1 remains the selected visual direction; neither the existing draft nor a replacement model is approved. Source assistant acknowledges the unsuitable base mesh and recommends replacing it rather than continuing minor appearance edits. Next visual action: owner selects a candidate model/link, then inspect actual formats, facial blink/mouth controls, license and Pi suitability before acquisition or integration. No replacement has been downloaded or verified by this synchronization; marketplace descriptions in the source reply are unverified here and are not purchase authorization.

VERIFIED synchronization evidence: source task completed, source refinement commit `eb39eb1d94b300f6290d4e7aa6f324e62b8ec8de` already on remote main, and [6 new extracted text messages](conversations/2026-09-13-01a0916f-avatar-rejected.md) through 10:55:19.600 UTC. Owner rejection is direct text evidence; screenshot pixels and source visual/test claims were not independently rechecked. The earlier refinement paragraph's `ccef30b` reference identifies the previous draft; the later refinement publication is `eb39eb1`. Pi performance, facial/audio integration and replacement quality remain NOT VERIFIED. Technical NEXT STEP ORDER and motor/encoder/driver/legacy-core service HOLD remain unchanged. Older backlog, image bytes and inaccessible account/cloud history remain outside this bounded archive.

### Accessible-message synchronization — 2026-09-13, avatar draft completion

[New bounded transcript](conversations/2026-09-13-01a0916f-avatar-increment.md) preserves 36 additional user/final-assistant text messages, including the 35 deferred while the source task was active. Coverage ends at 09:18:35.685 UTC; earlier backlog, image bytes and inaccessible account/cloud history remain outside this export. Source task is completed at this checkpoint; its final response confirms draft publication in `ccef30b`, which synchronization verified on remote main before documentation edits. No code or hardware changes are made by this synchronization; source test reports above were not rerun here.

Owner-selected concept 1 remains the approved visual direction, not approval of the adapted 3D draft. Latest source completion explicitly says the draft remains simpler than concept 1 and is not installed as the main UI. Next visual action is review/refinement of the draft's facial volumes and likeness; Pi performance, full-body motion and audio lip-sync remain unverified. All motor/encoder/driver and legacy-core service holds remain active. Existing technical NEXT STEP ORDER is unchanged.

### Animated 3D character trial — 2026-09-13

**Appearance refinement, following owner request:** revised the editable draft and GLB with smaller eye openings, fuller lip/cheek/jaw volumes, broader nasal bridge, warmer complexion/lip/orbital vertex colors, restrained PBR reflections and fine surface-following hair geometry. Fixed GLB color-layer selection: imported white COLOR_0 had hidden the new complexion COLOR_1; skin now explicitly uses the new layer. Viewer has closer portrait framing, directional fill/rim lighting and a three-quarter button. VERIFIED: updated Blender front/three-quarter renders, local browser front/oblique appearance, no JS errors in checked state; 48,103 vertices, 154 bones, 57 facial shape keys. Source/previous draft preserved in Git (ccef30b). PARTIALLY VERIFIED: existing sample movement with refined mesh, not exhaustive morph verification. NOT VERIFIED: realism or resemblance matching concept 1, Pi performance or integration. Current stock topology remains anime-like; next quality step requires deeper eyelid/nose/lip and hair-lock remodeling, not another claim of completion based on lighting. Main UI and hardware remain unchanged.

**Latest checkpoint — editable 3D draft requested:** created `assets/characters/aria-concept-01/aria-concept-01-draft.blend` and `.glb`, with front/three-quarter Blender renders, build report and retained source license settings. This is an adapted pixiv sample directed toward concept 1, NOT an image reconstruction or an approved high-detail likeness. Changes include face proportions/morphs, darker hair, PBR materials, indigo collar/trim and a six-second demonstration animation. Reproducible Blender builder: `tools/avatar/build_concept_01.py`. The source VRM and main standby avatar remain preserved; `/model-preview` is a separate viewer with orbit/zoom and motion toggle.

**VERIFIED:** Blender 5.2 export/render, 25,207 mesh vertices, 154 bones, 57 facial shape keys; GLB loaded/rendered in the local PC browser with two animation clips and advancing frame counters, no reported JS errors in the checked state. Fixed incorrect transparent-material export that previously obscured hair/face; current materials are opaque like the source. Existing 17 host tests and viewer JavaScript syntax checks pass. **PARTIALLY VERIFIED:** exported demonstration head/face animation; not every facial morph was visually checked. Body retains the authored T-pose because VRM sleeve constraints are not fully imported. **NOT VERIFIED:** concept-1 likeness/realistic quality, owner acceptance, full-body acting, audio lip-sync, Pi performance and deployment. Next visual step: review and refine facial volumes/proportions against concept 1 before main-UI integration. All hardware HOLD boundaries remain active.

Design-selection checkpoint (before the draft above): owner requests image concepts and has no character model file. Generated four standalone portrait concepts with built-in image_gen, saved under `docs/design/aria-face-concepts/` with exact prompts. VERIFIED: four PNG previews generated and preserved on D. They are static design images, NOT 3D models or evidence that this quality runs on Pi. Owner subsequently selects concept 1 ("mẫu 1 hợp nhất"): `docs/design/aria-face-concepts/01-long-hair.png` is the approved visual direction: long dark hair, warm brown eyes, soft facial volumes, restrained smile and indigo clothing. VERIFIED owner design choice; this does not approve the earlier stock VRM or the new draft.

Face-depth correction: owner wants fuller, softer depth, explicitly rejects sharper nose/chin. Current preview uses physical skin/eye materials with original UV textures, softer hemispheric/key/fill lighting, low skin specularity and restrained eye reflections. Runtime-only deformation reduces the sample's nose projection and gently lifts the central chin tip; the same deformation is applied to facial position morph targets. Source VRM bytes are unchanged. Camera is slightly closer, texture anisotropy capped at 4. Local browser rendering and expression switching checked without reported JS errors; Pi GPU cost and final visual acceptance remain NOT VERIFIED. These are improvements to the stock mesh, not a high-detail reconstruction of the supplied portrait.

Background follow-up: owner requests replacing the background. Current 3D view uses a muted rose/lavender gradient, brighter behind the character and dark at the circular edge, with pale clock/temperature text. CSS-only change visually checked in the local PC browser; Pi panel appearance remains NOT VERIFIED.

**Current visual direction:** owner requests moving 3D instead of a portrait, rejects the procedural head as ugly, then finds the stock VRM preview too plain. The rejected procedural file was kept only as a local temporary comparison, not shipped. Current preview uses pixiv's licensed VRM1_Constraint_Twist_Sample v1.0.1 through locally vendored Three.js r180 / three-vrm 3.4.2. Runtime styling adds lavender clothing, warmer hair, a small flower barrette, soft portrait fade and subdued colored background. Standby still contains only time, avatar and measured/unknown temperature. The stock character is NOT a reconstruction of the owner-selected photo and is NOT finally approved by the owner.

**VERIFIED (PC/local browser):** VRM asset loads from the app's explicit local route, WebGL renders the textured/skinned character with advancing frame counters, standby/main navigation works, original-photo selection remains available and disables the expression control, returning to 3D works, and no JS errors appeared in checked states. Existing 17 host tests pass after route/CSP changes; JavaScript syntax checked. All new project assets are on D. Source VRM is unchanged (10,776,032 bytes), license metadata/third-party notices retained in app_ui; libraries are MIT, model has VRM Public License 1.0 plus embedded settings, NOT CC0. No remote CDN request at runtime; blob access is limited to image/connection decoding while scripts remain same-origin.

**PARTIALLY VERIFIED:** animation code combines blink, gaze, hair spring motion, eased poses and spaced idle gestures (glance, tilt, smile, nod); pointer-following is a screen interaction, not camera tracking. Speaking mouth movement is state-driven, not audio/phoneme lip-sync. One canvas is reused, frames capped near 30fps with pixel ratio at most 1.25, drawing skips hidden/non-3D views and reduced-motion disables continuous motion. Loading/context failure has a photo fallback; context-loss recovery and reduced-motion behavior have not been fault-injected on the Pi.

**NOT VERIFIED:** actual Pi GPU/memory/frame rate, deployment, voice synchronization, resemblance to the supplied portrait and final owner visual acceptance. Motor/legacy-core HOLD and provider billing boundaries remain unchanged. Next visual checkpoint is owner review of this moving-character preview, then Pi performance verification before treating it as the deployed UI.

### Human-avatar trial — 2026-09-13

Current portrait selection supersedes the generated anime image: owner supplied `kling_20260517_作品_Image1Chib_5063_0.png` and explicitly requested using that face. Imported unchanged as `software/pi/app_ui/aria-owner-portrait-v1.png` (3,482,776 bytes); source/destination SHA-256 both `42b5beb8f64a1a1da5478ac991fc05002e79eeed1ceb93ebbda15619044005e7`. UI frames the landscape source with CSS object-fit/position and soft edge mask; no source pixel edits or regeneration. Standby/main now use this image, labeled owner-selected static portrait. Browser verified its rendering; clock/temperature and animated fallback remain. Source original and earlier asset preserved; facial animation and Pi runtime NOT VERIFIED.

Latest visual direction: owner wants a more detailed, lifelike anime female character. Added original ImageGen portrait `software/pi/app_ui/aria-anime-v1.png` (1,954,374 bytes), copied into the D-drive repo, as the default standby/main avatar. Existing illustrated SVG was refined (layered hair, almond eyes with clipped moving pupils, subtle nose/lips) and retained via **Cài đặt → Kiểu nhân vật → Avatar chuyển động**. Detailed portrait is explicitly labeled a STATIC IMAGE: no blink, gaze tracking, expression change or lip-sync; user was told this limitation before integration. Expression control is disabled for static portrait. Both visual options preserve time, real/unknown temperature, dialogue and service/motor holds. Browser checked detailed portrait rendering; existing 17 host tests passed after adding its explicit image route. Future image rigging/animation and actual Pi performance are NOT VERIFIED. Character artwork remains a trial, not final owner approval.

Latest owner choice: female avatar. Preview updated with longer brown/plum hair, delicate brows/lashes and rose lip contour; rendered in local browser. Existing gaze/blink/expressions preserved; still a character-design trial, not final approval.

Owner asks to try a human face. Current UI preview uses an original stylized human avatar with warm skin, brown hair/irises, ears, nose and lip contours, retaining procedural gaze/blink/expressions and clock/temperature. This is a visual trial, not an approved final character or a real person's likeness. Browser inspected the rendered preview. Earlier robot variants remain in Git history; hardware/backend unchanged, Pi rendering remains NOT VERIFIED.

### Color and depth follow-up — 2026-09-13

Latest owner correction: the oval face looked too round. Replaced its silhouette and shadow with a softly squared robot face, flatter forehead, straighter sides and a gently tapered lower edge; retained pupils, animation, color/depth and standby information. New silhouette visually checked in the local browser; actual Pi panel remains NOT VERIFIED.

Owner requests stronger 3D feel and more color. UI now uses a rounded blue/teal face with directional gradient lighting, rim highlights and cast shadow, shaded white eyeballs/green-turquoise irises, pink cheeks and a recessed mouth with clipped pink tongue. This is lightweight SVG depth shading, not a 3D mesh renderer. Existing eased poses, pupils/gaze, blink, reduced-motion behavior, clock/temperature and navigation are retained. Browser visually checked the new standby, expression selection and return to standby with no JS errors in checked state. Pi GPU/render performance remains NOT VERIFIED. No backend or hardware changes.

### Softer face with pupils — 2026-09-13

Owner requests a less rigid face with pupils. Updated native SVG renderer with softly shaded eye whites/irises, dark pupils/highlights, rounded brows and smile. Facial pose parameters interpolate instead of switching path shapes; small eased gaze shifts, randomized blink intervals and subtle vertical motion run with updates capped near 30fps. Hidden-tab drawing is skipped, hidden face elements are not updated, and reduced-motion preference suppresses gaze/blink/bobbing and pose animation. Browser checked rendered eyes/pupils, changing gaze transforms, happy-to-sad pose change and return to happy; no JS errors in checked state. These are UI animations only, not camera gaze tracking or audio lip-sync. Actual Pi rendering performance remains NOT VERIFIED. Clock/temperature, existing controls and hardware HOLD unchanged.
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

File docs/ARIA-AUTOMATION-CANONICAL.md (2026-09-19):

# ARIA Automation — CURRENT/CANONICAL

Status: CURRENT/CANONICAL
Created: 2026-09-19
Scope: ARIA PC automation only.

This is the single source of truth for the ARIA automation system. Do not create a second automation master, handoff, roadmap, or state document. Phase 1 operational state lives under `D:\UserData\ARIA\automation-state`. Phase 2 task packets live under the Git-ignored `automation/runtime/tasks`; runtime
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

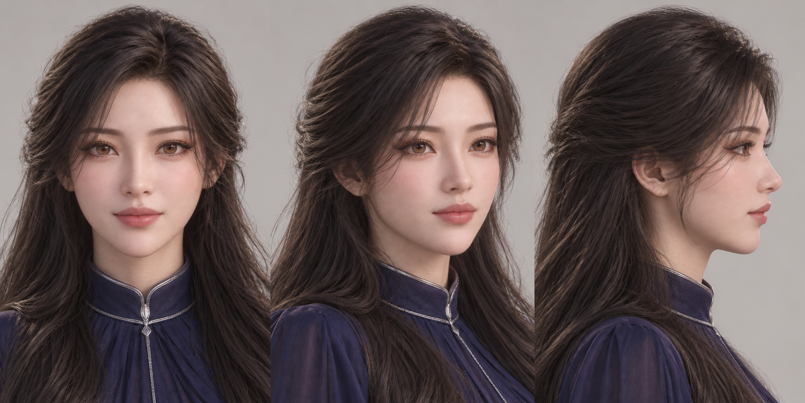
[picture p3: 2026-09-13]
docs/design/aria-face-concepts/01-turnaround-reference.png

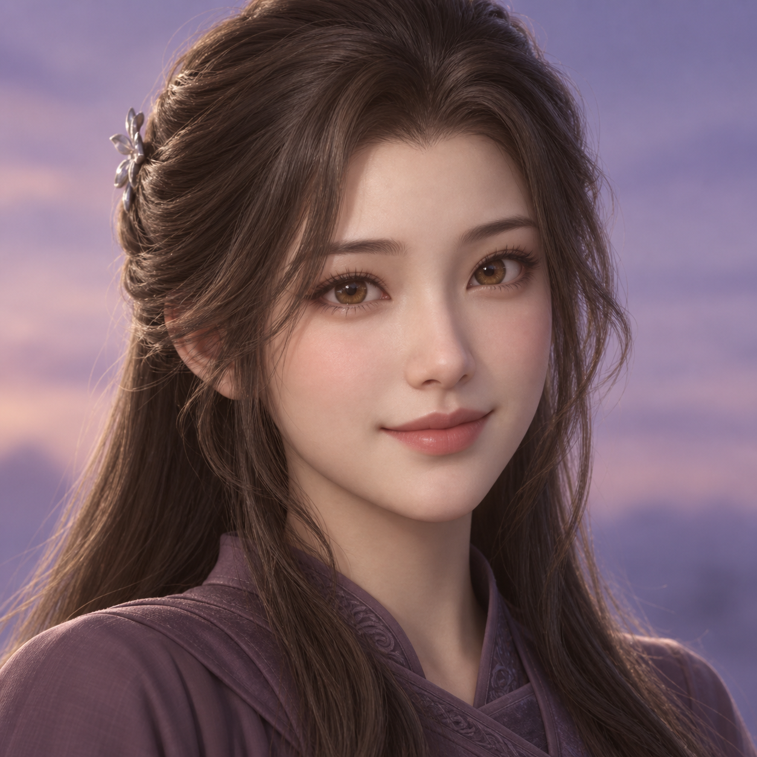
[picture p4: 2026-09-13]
docs/design/aria-face-concepts/04-half-up.png

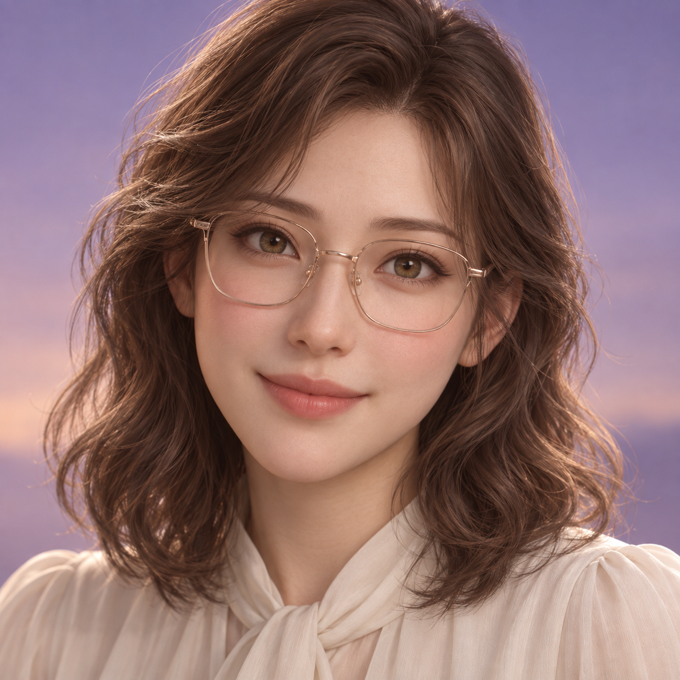
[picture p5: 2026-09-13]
docs/design/aria-face-concepts/02-glasses.png

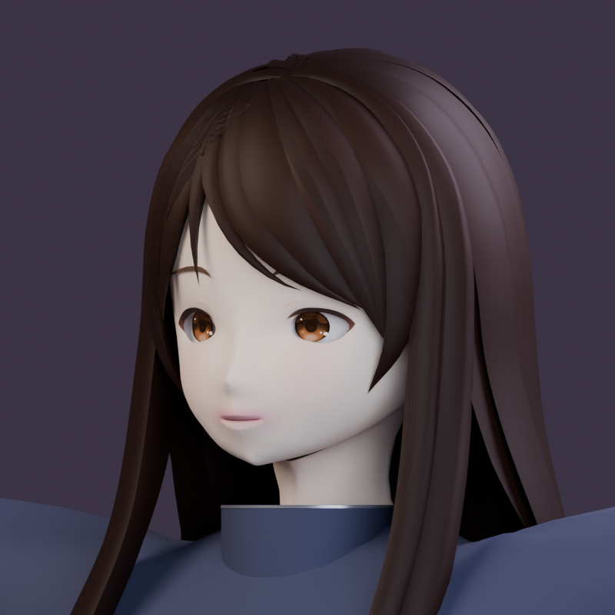
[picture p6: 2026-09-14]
assets/characters/aria-concept-01/three-quarter.png

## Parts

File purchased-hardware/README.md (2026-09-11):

# ARIA — Linh kiện đã mua và CAD

Nguồn chuẩn duy nhất cho BOM, trạng thái phần cứng hiện hành, số lượng mua và CAD là [`docs/ARIA-BOM-001.md`](../docs/ARIA-BOM-001.md).

Thư mục này giữ các file CAD và bằng chứng mua hàng. Cập nhật bảng linh kiện, trạng thái và kết quả đối chiếu CAD trong BOM; không tạo bảng sao chép tại đây.

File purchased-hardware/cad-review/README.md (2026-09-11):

# CAD review holding area

These files are preserved because they are unique or nominal, but they are **not** approved manufacturing CAD.

- `01-raspberry-pi-5-with-official-cooler_UNVERIFIED-MISMATCH.dwg`: includes an Official Active Cooler, while the purchased cooler was recorded as Smraza.
- `16-yd-esp32-s3-n16r8/`: the pinout evidence identifies the purchased PCB family as the 44-pin dual-USB-C YD-ESP32-S3 N16R8. The replacement 2D/3D CAD matches that family's nominal geometry, but tight enclosure dimensions still require measurement of the delivered board.

See [the canonical BOM](../../docs/ARIA-BOM-001.md) for hashes and decisions.

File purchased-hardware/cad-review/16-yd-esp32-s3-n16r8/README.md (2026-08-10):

# CAD — YD-ESP32-S3 N16R8

Trạng thái: **đúng họ PCB đã đặt, hình học danh nghĩa; chưa duyệt để chế tạo vỏ**.

## Nhận dạng

- Ảnh đơn hàng xác nhận tùy chọn `ESP32S3 N16R8`.
- [Ảnh pinout](../../evidence/16-esp32-s3-n16r8-pinout.png) cho thấy module `ESP32-S3-WROOM-1-N16R8`, 44 chân, hai cổng USB-C đặt cạnh nhau và RGB ở GPIO48.
- Bố trí này khớp họ `YD-ESP32-S3` của VCC-GND Studio; **không phải PCB Espressif ESP32-S3-DevKitC-1 chính hãng**.

## File giữ lại

- [`16-yd-esp32-s3-n16r8_dimensions.dwg`](16-yd-esp32-s3-n16r8_dimensions.dwg): bản vẽ 2D AutoCAD 2018.
- [`16-yd-esp32-s3-n16r8_dimensions.dxf`](16-yd-esp32-s3-n16r8_dimensions.dxf): nguồn 2D có layer và kích thước.
- [`16-yd-esp32-s3-n16r8_board.step`](16-yd-esp32-s3-n16r8_board.step): mô hình 3D board và bao linh kiện chính, không gồm header rời.
- [`16-yd-esp32-s3-n16r8_preview.png`](16-yd-esp32-s3-n16r8_preview.png): ảnh xem nhanh.

## Kích thước danh nghĩa

- PCB: **63.50 × 27.94 × 1.60 mm** (2.5 × 1.1 inch).
- Hai hàng, mỗi hàng 22 lỗ; pitch **2.54 mm**.
- Khoảng cách tâm hai hàng: **25.40 mm**.
- Lỗ header: **Ø1.00 mm**.
- Module WROOM-1: **18.00 × 25.50 mm**.
- Bao tổng có phần antenna: khoảng **27.94 × 70.00 mm**.
- PCB không có lỗ bắt vít.

Vị trí USB-C, nút nhấn và linh kiện nhỏ được tỷ lệ hóa từ ảnh, chỉ dùng kiểm tra va chạm sơ bộ. Sau khi nhận hàng phải đo lại bằng thước cặp trước khi khóa lỗ mở hoặc khoảng hở nhỏ hơn **±0.30 mm**.

## Kiểm tra file

- DWG đã được chuyển ngược sang DXF và audit thành công: 44 lỗ, 4 polyline, 7 đường kích thước và 6 ghi chú được giữ nguyên.
- SHA-256 DWG: `AC02E1AB0A3A8603DE5E4D959B0803804FB58B2BC3D3EA54220BD1A12CFD2851`
- SHA-256 DXF: `65C7996A3B58E00D73CCCD8FBEDDDFAD488881823C82CADE1EAF6D154DCFAF1D`
- SHA-256 STEP: `3F0E1DCD6B1FAE7410FC7D64DFDACE371CCCE45C28A794D921B2933200553FEF`

Nguồn đối chiếu: [YD-ESP32-S3 N16R8 trên CircuitPython](https://circuitpython.org/board/yd_esp32_s3_n16r8/), [tài liệu nhận dạng/pinout họ YD-ESP32-S3](https://github.com/profharris/YD-ESP32-S3_ESP32-S3-WROOM-1_Dev), và [tài liệu Espressif DevKitC-1 dùng để phân biệt PCB](https://docs.espressif.com/projects/esp-dev-kits/en/latest/esp32s3/esp32-s3-devkitc-1/user_guide_v1.1.html).

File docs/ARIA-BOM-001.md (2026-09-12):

# ARIA-BOM-001 — BOM và trạng thái phần cứng canonical

> **Đây là nguồn chuẩn duy nhất cho BOM, trạng thái phần cứng hiện hành, linh kiện đã mua, số lượng và CAD tương ứng.**
> Không sao chép bảng này sang file khác. ESP32-S3 N16R8 đã được bổ sung ở dòng 16.

Cập nhật: 2026-09-13

**Cập nhật hiện hành 2026-09-13, thay thế trạng thái nhận hàng/sự cố cũ bên dưới:** người dùng xác nhận đã có ESP thay thế cùng loại YD N16R8; không suy ra thêm số lượng mua hoặc giá. Encoder AS5600 bên trái hỏng, bên phải còn nối và đang chờ kiểm tra sau đổi chân; chưa xác nhận đã thay encoder trái. INA260 ×1 đã có và nối Pi; ảnh terminal xác nhận mã nhận dạng tại địa chỉ 0x40. Chi tiết số đo và giới hạn kiểm chứng nằm trong master. Các ghi chú “chưa nhận hàng” INA260 và “chưa xác nhận nhận board thay thế” trong snapshot dưới đây là lịch sử đã superseded.

Tiến độ, kết quả test và migration gaps nằm trong [MASTER HANDOFF](ARIA-MASTER-HANDOFF.md); không suy ra tiến độ dự án từ bảng mua hàng này.
Phạm vi bảng đã mua có hồ sơ trước migration (không phải toàn bộ phần cứng live): **15 hạng mục / 28 đơn vị ở snapshot lịch sử** (trước điều chỉnh INA260 xuống 1; không phải tổng đã nhận hiện tại); không cộng lại phần bảo vệ tích hợp trong cụm pin. Bánh xe hiện hành được ghi riêng bên dưới do chưa có số lượng mua được xác nhận.
Tổng chi phí đã ghi nhận: **khoảng ¥90,576** (gồm phí/thuế đơn truyền động; không dùng để suy ra giá từng dòng)

## Danh sách đã mua

| # | Nhóm | Linh kiện / model đã mua | SL | CAD hiện có | Kết luận |
|---:|---|---|---:|---|---|
| 1 | Compute | Raspberry Pi 5 4GB | 1 | [Pi 5 + Official Cooler](../purchased-hardware/cad-review/01-raspberry-pi-5-with-official-cooler_UNVERIFIED-MISMATCH.dwg) | **Sai một phần:** cooler trong file là loại chính hãng, cooler mua là Smraza; chưa kiểm kích thước. |
| 2 | Power sensing | Board INA260 đo dòng điện / điện áp / công suất qua I²C; DigiKey **1528-2955-ND**; board code **4226** | 1 | — | **Đã có, đã nối Pi** theo xác nhận 2026-09-13; mã nhận dạng INA260 đọc được tại **0x40**. Chưa xác minh routing IN+/IN−, độ chính xác hoặc full-load bench. Thiếu CAD/revision. |
| 3 | Thermal | Smraza Active Cooler cho Raspberry Pi 5, 5V PWM 4-pin | 1 | — | Thiếu. |
| 4 | Power | Pololu D24V90F5, 5V/9A | 1 | — | Thiếu. |
| 5 | Vision | Raspberry Pi Camera Module 3 Wide NoIR | 1 | [DWG](../purchased-hardware/cad/05-raspberry-pi-camera-module-3-wide-noir.dwg) | Đúng tên model; chưa kiểm scale, lỗ bắt, lens keep-out và kích thước. |
| 7 | Audio input | reSpeaker / XMOS XVF3800 4-Mic Array | 1 | — | Thiếu; cần xác minh revision/USB variant. |
| 8 | Audio output | Loa thay thế JBL GO2 | 1 | — | Thiếu; cần đo outline, lỗ bắt, trở kháng và đầu nối. |
| 9 | Charging | Module IP2368, 3S USB-C PD, hai chiều 100W theo listing | 1 | — | Thiếu; cần xác minh board/revision. |
| 10 | Amplifier | Module MAX98357A I²S Class-D | 2 | — | **2 board mới, cả 2 đều OK** theo xác nhận của người dùng; thiếu CAD, cần xác minh layout board cụ thể. |
| 11 | Display | Waveshare Round DSI 4-inch, cảm ứng điện dung | 1 | — | Thiếu; chưa xác minh revision và bộ cáp. |
| 12 | Battery cells | Cell 18650, listing ghi “35E / 3.7V / 3000mAh” | 10 | — | Thiếu; tên 35E và dung lượng 3000mAh mâu thuẫn, phải kiểm mã in/capacity khi nhận. |
| 13 | IMU | Adafruit BNO085 9-DOF breakout | 1 | — | Thiếu. |
| 14 | Drive | DFRobot FIT1035 2208 BLDC, tích hợp encoder từ AS5600 | 2 | — | Thiếu; không cần encoder rời. |
| 15 | Motor driver | DFRobot DRI0058 SimpleFOCMini | 2 | — | Thiếu. |
| 16 | Real-time control | YD-ESP32-S3 / ESP32-S3-WROOM-1-N16R8, 44 chân, dual USB-C ([đơn hàng](../purchased-hardware/evidence/16-esp32-s3-n16r8-order.png), [pinout](../purchased-hardware/evidence/16-esp32-s3-n16r8-pinout.png)) | 1 | [Bộ CAD 2D/3D](../purchased-hardware/cad-review/16-yd-esp32-s3-n16r8/README.md) | Đã đặt ngày 2026-08-07, ¥1,496; họ PCB canonical theo ảnh. **Board cũ cháy; người dùng xác nhận đã có board thay thế cùng loại YD N16R8 ngày 2026-09-13. Chưa có hồ sơ giá/số lượng mua mới; không cộng thêm số lượng mua.** Báo cáo test trước sự cố là lịch sử. Chưa đối chiếu exact revision của board test; CAD còn phải đo bo thực tế. |

## Cấu hình hiện hành do người dùng xác nhận

Cấu hình được chốt ngày 2026-09-11 và bổ sung từ migration snapshot ngày 2026-09-12 theo xác nhận của người dùng. Các ID trong bảng đã mua được giữ ổn định để không làm sai tham chiếu CAD; ID 6 được bỏ khỏi bảng linh kiện rời, xem phần nội bộ pin bên dưới. Tổng chi phí vẫn là số đã ghi nhận, không suy ra chi phí mới từ thay đổi cách đếm.

### Bổ sung cấu hình live từ migration 2026-09-12

Nguồn: xác nhận trực tiếp của người dùng trong yêu cầu migration; xem evidence/mức test ở master handoff. Không cộng các mục sau vào tổng 15 hạng mục / 28 đơn vị hoặc tổng chi phí cũ khi chưa có hồ sơ mua đối chiếu.

- microSD **128GB** đang dùng trên Pi; chưa có exact SKU/hồ sơ mua ở repo. Thay spec 64GB trong lịch sử.
- **BME280** là sensor môi trường hiện hành; chưa có exact board/revision, số lượng mua và CAD được đối chiếu. SHT45 lịch sử không phải cấu hình live.
- **VL53L1X ×4** theo snapshot người dùng; chưa có carrier/revision, hồ sơ mua và CAD. Không tiếp tục dùng số lượng 6 từ BOM cũ như inventory hiện tại.
- **AS5600 ×2**: bảng dòng 14 ghi tích hợp trong hai FIT1035; không cộng thêm encoder rời.
- Màn hình AliExpress đã chạy theo snapshot; tên Waveshare ở dòng 11 là định danh đang lưu, exact revision/bộ cáp và vùng tròn cần đối chiếu, không tự thay model.

Số lượng INA260 hiện hành: **1 board**, theo điều chỉnh trực tiếp của người dùng ngày 2026-09-12; thay cho số lượng 2 trước đó. Board đã có, nối vào Pi và được nhận dạng tại 0x40 theo bằng chứng người dùng ngày 2026-09-13; routing IN+/IN−, ALERT và accuracy/full-load chưa xác nhận. Tổng chi phí lịch sử không được tự giảm khi chưa có hồ sơ đơn hàng cập nhật.

### Bánh xe

- Loại lốp: **gravel tire**.
- Đường kính ngoài **Ø60 mm**, bề rộng lốp **22 mm**.
- Ảnh được người dùng mô tả ghi **center/hub dimension 12 mm**; chưa xác định đó là đường kính lỗ trục hay kích thước khác của hub.
- Khối lượng ghi trên ảnh: **108.8 g/set**; chưa xác nhận số bánh trong một set, không diễn giải thành khối lượng mỗi bánh.
- Số lượng mua, mã sản phẩm và CAD chưa được xác nhận trong lần cập nhật này. Dùng thông số hiện hành để lập kế hoạch cơ khí; đo bánh/hub thực tế trước khi chốt lắp ghép.

### Nội bộ cụm pin, bảo vệ và sạc

- **BMS 3S đã tích hợp bên trong cụm pin**, không phải linh kiện standalone trong BOM hoặc hardware summary.
- Chỉ đề cập BMS trong nội bộ pin, bảo vệ, sạc hoặc ghi chú lịch sử. Kiểm tra chức năng bảo vệ của cụm pin khi thử nguồn/sạc.
- Kiến trúc **3S**; kế hoạch **18650 3S3P / 9 cell**, candidate **Samsung INR18650-35E** theo migration snapshot, chỉ **planned/not confirmed inventory**. Không có xác nhận pack đã lắp đúng cấu hình này.
- Thông tin 10 cell đã ghi nhận trong bảng không tự xác định cấu hình lắp pack, số cell dự phòng hoặc xác nhận Samsung 35E chính hãng; mâu thuẫn listing vẫn mở.

### Lịch sử thay đổi / superseded

- INA226 đã được thay thế hoàn toàn bởi INA260 ×1 tại dòng 2; không dùng INA226 trong thiết kế, wiring hoặc firmware hiện hành.
- Trạng thái MAX98357A cũ “1 tốt, 1 hỏng” đã bị thay thế bởi 2 board mới, cả 2 đều OK.
- Bánh xe Ø40 × 20 mm đã obsolete; thông số hiện hành nằm ở mục Bánh xe.
- Dòng BMS rời ID 6 trước đây ghi 3S Li-ion, 20A + NTC. Đây là dữ liệu lịch sử, không xác nhận rating/model của BMS bên trong cụm pin hiện tại.
- BOM được đưa về `docs/ARIA-BOM-001.md`; `purchased-hardware/README.md` chỉ dẫn tới nguồn chuẩn này.

## Kết quả đối chiếu CAD

Các đường dẫn trong cột File repo bên dưới tính từ `purchased-hardware/`.

- **1 file đúng tên model nhưng chưa xác minh kích thước:** Camera Module 3 Wide NoIR.
- **1 file sai một phần:** Raspberry Pi 5 ghép với **Official Active Cooler**, không khớp cooler **Smraza** đã mua.
- **1 bộ CAD đúng họ PCB YD-ESP32-S3 N16R8:** ảnh pinout xác nhận 44 chân, dual USB-C và RGB GPIO48. DWG DevKitC-1 cũ sai PCB đã bị thay bằng DWG/DXF 2D và STEP 3D kích thước danh nghĩa; vẫn nằm trong `cad-review/` cho đến khi đo bo thực tế.
- **12 hạng mục trong bảng đã mua hoàn toàn chưa có CAD trong repo.** Bánh xe hiện hành cũng chưa có CAD; chưa tính vào bảng đã mua vì chưa xác nhận số lượng.
- **Không phát hiện CAD trùng SHA-256** trong các file đang giữ.
- **Chưa có CAD nào được xác minh đủ để chế tạo.**

### Dấu vết CAD đang giữ

| Phân loại | File repo | File gốc đã ghi nhận | SHA-256 | Quyết định |
|---|---|---|---|---|
| Ứng viên đúng model | `cad/05-raspberry-pi-camera-module-3-wide-noir.dwg` | `ARIA-SEN-001_Camera-Module-3-Wide-NoIR_colored.dwg` | `D3B28B76AD57CCA2DB5FC2A12D78417A592557A5F56D5D4C3DAAEA016415A2BE` | Giữ; cần đo/đối chiếu datasheet. |
| Sai một phần | `cad-review/01-raspberry-pi-5-with-official-cooler_UNVERIFIED-MISMATCH.dwg` | `ARIA-CPU-001_colored-final.dwg` | `54B941F2210CF043CEC7F9E826D32738850710780BBC9B49B460F33F7F667A4F` | Giữ; không coi là CAD của cooler đã mua. |
| Đúng họ PCB, kích thước danh nghĩa | `cad-review/16-yd-esp32-s3-n16r8/` | Bộ YD-ESP32-S3 N16R8 đã tạo trên máy | DWG `AC02E1…D2851`; DXF `65C799…AF1D`; STEP `3F0E1D…53FEF` | Thay file DevKitC-1 sai loại; giữ ở review cho đến khi đo bo nhận được. |

## Quy tắc duy trì

1. Chỉ thêm một dòng khi có bằng chứng đã đặt/mua.
2. Model, số lượng và trạng thái CAD chỉ sửa trong file này.
3. Không tạo BOM, purchase register hoặc CAD-status thứ hai. Các tài liệu kỹ thuật dẫn tới BOM này; cấu hình người dùng đã chốt nhưng chưa đủ dữ liệu mua được ghi ở phần cấu hình hiện hành, không tự thêm số lượng vào bảng đã mua.
4. Không gọi CAD là “verified” nếu chưa kiểm units, kích thước tổng, lỗ bắt, đầu nối và keep-out.
5. Không đưa linh kiện dự kiến mua vào bảng. ESP32-S3 ở dòng 16 đã xác định đúng họ YD-N16R8 nhưng vẫn phải đo PCB/revision thực tế khi nhận.

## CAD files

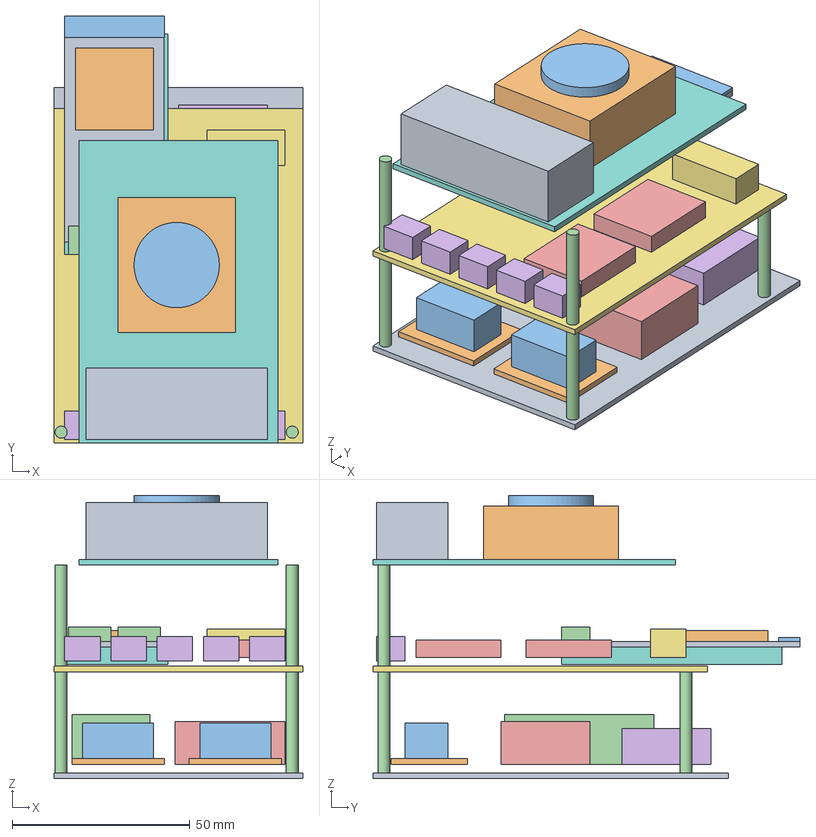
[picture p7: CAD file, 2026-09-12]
electronics/layout/stack-r3/ARIA_STACK_R3_ASSEMBLED_CONCEPT.step
70.0 x 120.0 x 79.6 mm
BASE_70x100_CONFIRMED_OUTLINE_ONLY
DRIVER_ENVELOPE_5
DRIVER_COMPONENT_ALLOWANCE_5
DRIVER_ENVELOPE_38
DRIVER_COMPONENT_ALLOWANCE_38
POLOLU_PLACEHOLDER
IP2368_PLACEHOLDER
INA260_PLACEHOLDER
LOGIC_CARRIER_PLACEHOLDER
ESP_SOCKET_ENVELOPE
ESP_YD_NOMINAL_BOARD
ESP_MODULE_SHIELD_PLACEHOLDER
ESP_ANTENNA_CLEAR_ALL_LAYERS
ESP_USB_ACCESS_4
ESP_USB_ACCESS_18
AMP_PLACEHOLDER_12
AMP_PLACEHOLDER_43
ISOLATED_POWER_BANK_GND
ISOLATED_POWER_BANK_VBAT
ISOLATED_POWER_BANK_5V
ISOLATED_POWER_BANK_3V3_PI
ISOLATED_POWER_BANK_3V3_ESP
PI_SENSOR_CONNECTOR_PLACEHOLDER
PI5_OUTLINE_56x85_NOMINAL
PI_PORT_ENVELOPE_PLACEHOLDER
COOLER_ENVELOPE_PLACEHOLDER
FAN_PLACEHOLDER
STANDOFF_CONCEPT
STANDOFF_CONCEPT001
STANDOFF_CONCEPT002
STANDOFF_CONCEPT003
STANDOFF_CONCEPT004
STANDOFF_CONCEPT005

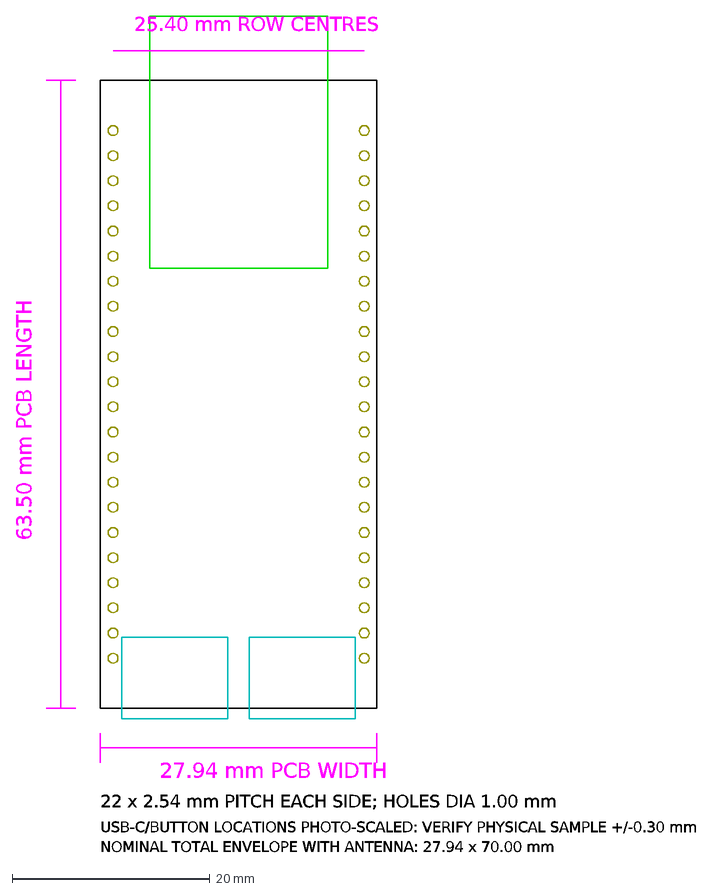
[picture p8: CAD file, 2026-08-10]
purchased-hardware/cad-review/16-yd-esp32-s3-n16r8/16-yd-esp32-s3-n16r8_dimensions.dxf
27.94 mm PCB WIDTH
63.50 mm PCB LENGTH
25.40 mm ROW CENTRES
22 x 2.54 mm PITCH EACH SIDE; HOLES DIA 1.00 mm
USB-C/BUTTON LOCATIONS PHOTO-SCALED: VERIFY PHYSICAL SAMPLE +/-0.30 mm
NOMINAL TOTAL ENVELOPE WITH ANTENNA: 27.94 x 70.00 mm

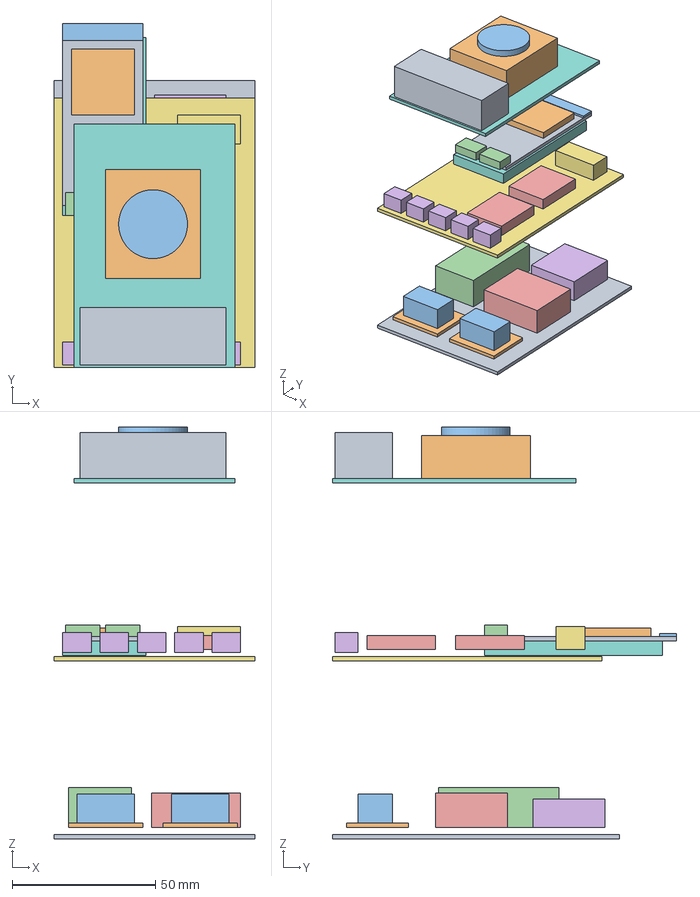
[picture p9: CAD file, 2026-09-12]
electronics/layout/stack-r3/ARIA_STACK_R3_EXPLODED_CONCEPT.step
70.0 x 120.0 x 143.6 mm
BASE_70x100_CONFIRMED_OUTLINE_ONLY
DRIVER_ENVELOPE_5
DRIVER_COMPONENT_ALLOWANCE_5
DRIVER_ENVELOPE_38
DRIVER_COMPONENT_ALLOWANCE_38
POLOLU_PLACEHOLDER
IP2368_PLACEHOLDER
INA260_PLACEHOLDER
LOGIC_CARRIER_PLACEHOLDER
ESP_SOCKET_ENVELOPE
ESP_YD_NOMINAL_BOARD
ESP_MODULE_SHIELD_PLACEHOLDER
ESP_ANTENNA_CLEAR_ALL_LAYERS
ESP_USB_ACCESS_4
ESP_USB_ACCESS_18
AMP_PLACEHOLDER_12
AMP_PLACEHOLDER_43
ISOLATED_POWER_BANK_GND
ISOLATED_POWER_BANK_VBAT
ISOLATED_POWER_BANK_5V
ISOLATED_POWER_BANK_3V3_PI
ISOLATED_POWER_BANK_3V3_ESP
PI_SENSOR_CONNECTOR_PLACEHOLDER
PI5_OUTLINE_56x85_NOMINAL
PI_PORT_ENVELOPE_PLACEHOLDER
COOLER_ENVELOPE_PLACEHOLDER
FAN_PLACEHOLDER

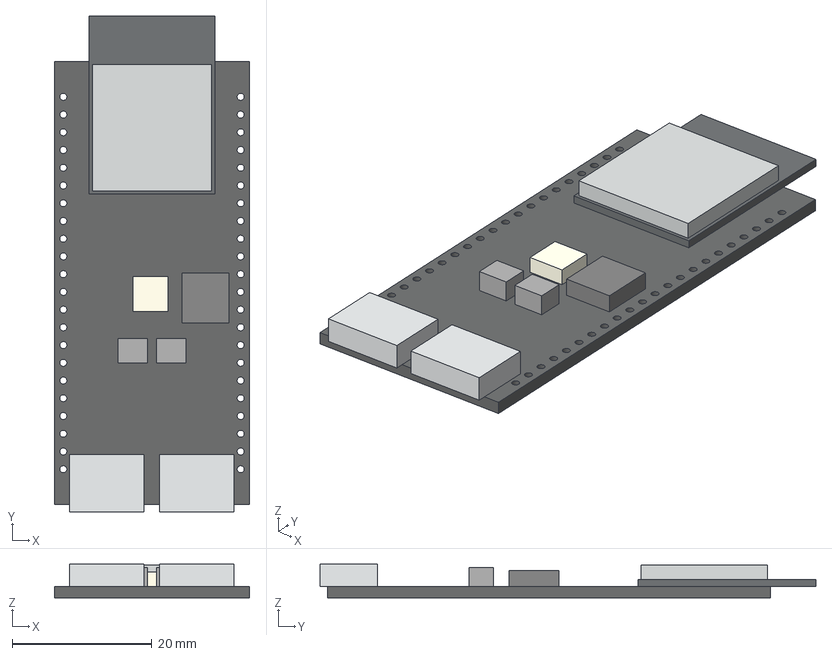
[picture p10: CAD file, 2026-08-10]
purchased-hardware/cad-review/16-yd-esp32-s3-n16r8/16-yd-esp32-s3-n16r8_board.step
27.9 x 71.0 x 4.80 mm
PCB_63p50x27p94
ESP32-S3-WROOM-1_module_pcb
ESP32-S3-WROOM-1_N16R8_shield
USB_C_1_ENVELOPE
USB_C_2_ENVELOPE
BOOT_button_envelope
RST_button_envelope
RGB_LED_envelope
LDO_envelope

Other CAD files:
purchased-hardware/cad-review/01-raspberry-pi-5-with-official-cooler_UNVERIFIED-MISMATCH.dwg
purchased-hardware/cad/05-raspberry-pi-camera-module-3-wide-noir.dwg
assets/characters/aria-concept-01/aria-concept-01-draft.blend
assets/characters/aria-custom/aria-custom-sculpt.blend
assets/characters/aria-custom/aria-head-blockout-r1.blend
assets/characters/aria-custom/aria-head-r2.blend
assets/characters/aria-custom/aria-head-r3.blend
assets/characters/aria-custom/aria-head-r4.blend
assets/characters/aria-custom/aria-head-r5.blend
assets/characters/aria-custom/aria-human-base.blend
assets/characters/aria-custom/r10-multiview/aria-head-r10.blend
assets/characters/aria-custom/r11-hair-fit/aria-head-r11.blend
assets/characters/aria-custom/r12-unified-hair/aria-head-r12.blend
assets/characters/aria-custom/r13-appearance/aria-head-r13.blend
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

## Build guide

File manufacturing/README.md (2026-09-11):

# ARIA manufacturing

Reviewed release checklists and fabrication packages may be stored here.

Do not copy the BOM or CAD inventory into this directory. The only purchased-hardware source is [`docs/ARIA-BOM-001.md`](../docs/ARIA-BOM-001.md). Every future release must identify its source commit, passed checks and explicit approval.

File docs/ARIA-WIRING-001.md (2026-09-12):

# ARIA-WIRING-001 — Wiring and safety rules

Purchased component identity and quantity come only from [`docs/ARIA-BOM-001.md`](ARIA-BOM-001.md).

Latest wiring checkpoint (2026-09-13): owner identifies connected encoder as RIGHT, initially SDA36/SCL37, then acknowledges remap to SDA4/SCL5 after receiving both new assignments. Left SDA8/SCL9 is reserved; left encoder is damaged and must remain disconnected. Motor power owner-confirmed unplugged. New diagnostic `firmware/esp32/ARIA_ENCODER_CHECK_R1` reads only the right bus with driver EN held LOW after setup. No physical continuity, supply or reset EN verification; carrier is still not released. INA260 is now connected to Pi per owner and its identification registers match at 0x40; exact physical supply/SDA/SCL and IN+/IN- routing remain unverified. Earlier pending-delivery/address-TBD statements are historical, superseded for receipt/address only. See master for screenshot evidence.

- Battery and motor current must not pass through breadboards or low-current buttons.
- Use short, fused, strain-relieved high-current wiring.
- Route motor phases and switching power away from audio, camera, IMU and control wiring.
- Verify connector polarity, wire gauge, current derating and service disconnects.
- Keep replaceable parts disconnectable.
- Prove motor stop behavior for loss of the main computer, controller reset and sensor faults.
- The canonical controller family is recorded in the BOM. Pi↔ESP32 protocol and integrated wiring still need validation; controller selection is no longer waiting for an inventory entry.
- Preserve the historical bench pinmap and unresolved pin holds in the [master handoff](ARIA-MASTER-HANDOFF.md#pinmap-bench-được-bảo-tồn--chưa-là-pinmap-tích-hợp-đã-release). The former ESP ToF mapping is historical. For a replacement N16R8 board, follow the proposed PCB revision below: do not allocate memory pins GPIO35/36/37.

This file intentionally contains no connector BOM, component list or CAD status copy.

## Power sensing and battery protection

Use INA260 for current power-sensing wiring; board identity and quantity are in the canonical BOM. Verify the delivered boards and I²C address configuration before finalizing the harness. Battery protection uses the 3S BMS inside the battery pack; validate the pack protection and charging connections as part of the battery assembly.

## Previous captured signal mapping — 2026-09-12 (preserved evidence, not replacement-PCB wiring)

Sources: imported Pi Core V0.6 / ESP Drive V0.3 and user-supplied D:/UserData/Downloads/PROJECT_ARIA_LATEST_PINOUT_HANDOFF_2026-09-12.md. GPIO numbers below are BCM numbers on Pi and GPIO numbers on ESP32, not physical header positions. This is a documented signal baseline, not a complete released power/connector schematic or a new physical continuity test. Preserve wiring; do not remap from historical KST/ESP sensor tables.

| Connection | Mapping | Evidence |
|---|---|---|
| ESP32 → left driver | GPIO15/16/17 → IN1/IN2/IN3; GPIO18 → EN | Capture and supplied pinout agree |
| ESP32 → right driver | GPIO11/12/13 → IN1/IN2/IN3; GPIO14 → EN | Capture and supplied pinout agree |
| Left AS5600 | ESP SDA38 / SCL35; controller 0 | Capture and supplied pinout agree; exact memory/build compatibility still unverified |
| Right AS5600 | ESP SDA36 / SCL37; controller 1 | Capture and supplied pinout agree; exact memory/build compatibility still unverified |
| Pi ↔ ESP32 | USB Serial /dev/ttyACM0, 115200 baud | Capture and supplied pinout agree; no GPIO UART required by this source |
| Pi sensor I2C | SDA GPIO2 / SCL GPIO3 | Dùng chung BME280/BNO085/4 ToF/INA260; owner-supplied GPIO/scan evidence, physical harness chưa được trợ lý kiểm tra |
| ToF S1–S4 XSHUT | Pi GPIO22/23/24/25 respectively | Capture and supplied pinout agree |
| ToF S1–S4 addresses | 0x30/0x31/0x32/0x33 after initialization | Capture and supplied pinout agree; assigned addresses, not power-on defaults |
| BME280 / BNO085 | Pi I2C, 0x76 / 0x4A | Capture and supplied pinout agree |
| INA260 | Pi I2C, 0x40 | Owner-supplied scan + ID-register evidence; ALERT không dùng/chưa gán, routing IN+/IN− chưa xác nhận |
| MAX98357A I2S | Pi GPIO18 BCLK / GPIO19 LRC / GPIO21 DOUT | Supplied pinout only; overlays, channel selection and physical wiring still need capture |
| Camera | Pi CAM/DISP0 | Supplied pinout; code checks imx708_wide_noir |
| Microphone | Pi USB; ALSA hw:1,0 at reported test | Capture and supplied pinout agree; card numbering is not a permanent device identity |
| Display | Pi CAM/DISP1 / DSI-2; rotation 180 degrees | Supplied pinout only; runtime boot/display configuration not captured |

Reported display overlay: dtoverlay=vc4-kms-dsi-waveshare-panel-v2,4_0_inch_c. Keep as reported configuration pending runtime capture, not a command to apply automatically.

The supplied pinout explains that ESP GPIO41/42/47/48 ToF mapping belongs to the former sensor-on-ESP architecture. It is not the current documented ToF mapping; GPIO48/RGB is not a current ToF collision under the Pi mapping. Exact board/build provenance for encoder GPIO35/36/37 remains separate.

INA260 pending-delivery text is superseded: one board is installed on the shared Pi I2C bus and identified at 0x40. Physical supply pins, ALERT, ground return and IN+/IN− branch remain unverified; do not infer them from address evidence. Power input, connector polarity, protection, motor phase order, encoder supply and amplifier channel/SD straps are not fully specified by this signal table and must not be invented.

## Replacement carrier PCB — proposed signal allocation R1

Status: DESIGN PROPOSAL / NOT RELEASED FOR SOLDERING OR FABRICATION. User reported ESP burned and requested pin optimization for a new PCB, confirming replacement is the same board type, YD-ESP32-S3 N16R8. Assume a carrier connecting existing modules; integration of bare power/driver ICs and PCB dimensions are not specified. Historical firmware/capture is preserved and has NOT been edited to this map. Do not run captured firmware on the new map.

### Why change the encoder pins

Espressif WROOM-1 datasheet v1.8 Table 1-1 identifies N16R8 as Octal PSRAM; Table 3-1 note b explicitly reserves IO35/36/37 for that memory. New encoder allocation must avoid those pins regardless of historical PASS labels. GPIO4/5/8/9 are general-purpose module I/O and appear on the stored YD family pinout. This establishes a design constraint, not the cause of the burned board or proof of the old board identity/build.

### ESP32 signal allocation (GPIO labels, not header pad numbers)

| Net | ESP GPIO proposed | Previous GPIO | Endpoint |
|---|---:|---:|---|
| ESP_MOTOR_L_IN1 | 15 | 15 | Left DRI0058 IN1 |
| ESP_MOTOR_L_IN2 | 16 | 16 | Left DRI0058 IN2 |
| ESP_MOTOR_L_IN3 | 17 | 17 | Left DRI0058 IN3 |
| ESP_MOTOR_L_EN | 18 | 18 | Left DRI0058 EN |
| ESP_MOTOR_R_IN1 | 11 | 11 | Right DRI0058 IN1 |
| ESP_MOTOR_R_IN2 | 12 | 12 | Right DRI0058 IN2 |
| ESP_MOTOR_R_IN3 | 13 | 13 | Right DRI0058 IN3 |
| ESP_MOTOR_R_EN | 14 | 14 | Right DRI0058 EN |
| ESP_ENC_L_SDA | 8 | 38 | Left FIT1035 encoder SDA, I2C controller 0 |
| ESP_ENC_L_SCL | 9 | 35 | Left FIT1035 encoder SCL, I2C controller 0 |
| ESP_ENC_R_SDA | 4 | 36 | Right FIT1035 encoder SDA, I2C controller 1 |
| ESP_ENC_R_SCL | 5 | 37 | Right FIT1035 encoder SCL, I2C controller 1 |

Keep separate encoder buses; do not short their SDA/SCL nets together. Both keep their own 3.3V pull-up network, accounting for resistors already on the encoder boards. Values and bus speed need cable-capacitance/rise-time checks; no blanket pull-up installation in parallel. Manufacturer specifies FIT1035 encoder operation at 3.3V; do not confuse motor 12V with encoder supply.

Reserve ESP19/20 for native USB; preserve 0/3/45/46 boot strapping; do not allocate flash/PSRAM signals (including 35–37); leave RGB48, UART0 43/44 and JTAG39–42 out of peripheral allocation. GPIO6/7/10/21/38/47 remain unassigned by this draft; do not treat them as final assignments for optional switches/faults without a circuit. ESP CHIP_EN/RST is not the same signal as either MOTOR_EN.

### Pi 40-pin header — retained signals

Physical numbers below apply to the Pi header viewed from its component side with pin 1 identified; they do not describe the mirrored solder side of a carrier. Pi GPIO and ESP GPIO are separate electrical nets even when their numeric suffixes match.

| Net/function | Pi BCM GPIO | Pi physical header pin | Endpoint |
|---|---:|---:|---|
| PI_I2C_SDA | 2 | 3 | Shared BME280/BNO085/ToF/INA260 SDA |
| PI_I2C_SCL | 3 | 5 | Shared BME280/BNO085/ToF/INA260 SCL |
| PI_TOF1_XSHUT | 22 | 15 | S1 XSHUT |
| PI_TOF2_XSHUT | 23 | 16 | S2 XSHUT |
| PI_TOF3_XSHUT | 24 | 18 | S3 XSHUT |
| PI_TOF4_XSHUT | 25 | 22 | S4 XSHUT |
| PI_I2S_BCLK | 18 | 12 | Both MAX98357A BCLK |
| PI_I2S_LRCLK | 19 | 35 | Both MAX98357A LRC |
| PI_I2S_DOUT | 21 | 40 | Both MAX98357A DIN |

Supply pin identification only: Pi 3.3V is physical 1/17; 5V is 2/4; GND is 6/9/14/20/25/30/34/39. This is NOT approval to feed Pi from the carrier header. Keep Pi/ESP 3.3V regulator outputs separate; shared GND does not mean parallel power outputs. Do not connect 5V to any signal GPIO. Pi GPIO0/1 (physical27/28) remain reserved for HAT identification; unused pins remain NC in this carrier draft. INA260 uses the shared I2C signals at 0x40; its physical supply/IN+/IN−/ALERT routing is still not released.

Camera retains CAM/DISP0; display retains CAM/DISP1 and reported DSI overlay; microphone remains USB; ESP link remains native USB. Use original FFC/USB connectors and cables for these links, not hand-routed substitute CSI/DSI or USB data traces. Fan uses existing Pi fan connector, not a newly assigned GPIO. MAX98357A left/right channel and shutdown straps remain to verify; shared I2S wiring alone does not select stereo. Speaker outputs are differential: do not join speaker negative outputs to logic ground or each other.

### Power and PCB organization

- For isolated replacement-controller bring-up, use one USB power source for ESP at a time with all suspect encoder/driver harnesses disconnected. For the carrier proposal, ESP supply comes through the Pi native-USB link; do not also connect carrier 5V or 3.3V as an ESP supply input. Verify actual YD power routing before a different dual-source scheme. USB and signal grounds are common, not galvanically isolated; provide intentional ground returns so motor current does not use USB/encoder/Pi wiring.
- Separate protected motor-power branches from regulated 5V electronics and 3.3V logic. Do not join Pi and ESP regulator outputs or driver auxiliary 3.3V outputs. DRI0058 auxiliary 3.3V is rated only 10mA by the manufacturer: never power ESP from it. Trace widths, connector current ratings, fuse values and power-entry topology require actual loads/board specifications; not assigned by pin selection.
- Place ESP on replaceable sockets if mechanical space permits, leave USB/BOOT/RESET accessible, respect antenna keep-out. Put each driver connection and encoder connector in distinct labeled groups, keep motor phase/high-current paths away from encoder/I2C/audio. Use continuous intentional reference/return routing; do not casually split ground planes under signals.
- Label nets with ESP_/PI_ prefixes, rail voltage, connector pin1 and component-side orientation. Give left/right encoders separate keyed connectors and check their actual GH1.25 cable order; do not infer it from wire color. Driver revision controls physical IN1/IN2/IN3/EN order. No physical YD pad numbering, connector footprint, or mirrored solder layout is released until replacement board and connector orientation are checked.
- Provide EN default-low circuitry near both drivers, test points for rails/GND/SDA/SCL/EN, and provision for an independent motor-disable path. Pulldown values and hard-stop circuit still need schematic review; a GPIO-only stop is not a completed hardware E-stop. Driver outputs must remain disabled with ESP absent/reset/unpowered and through power sequencing.
- Current source calls driver.init and initFOC during startup; it can energize motors before normal control is ready. A passive EN pulldown alone does not defeat an actively driven HIGH. Firmware gating, encoder-failure behavior, command timeout and disable/reset tests remain required before connecting motor power.

### Incident recovery and release checklist

- [x] User specifies same YD N16R8 replacement family.
- [x] Propose conflict-free per-controller signal allocation and retain captured baseline.
- [ ] Identify failed component and incident supply path; inspect isolated harnesses for shorts/reversal before reuse. Encoder condition is UNKNOWN, not presumed damaged or passed.
- [ ] Confirm replacement markings/revision, connector orientation, PCB type/dimensions and module footprints.
- [ ] Check each isolated encoder with correctly limited 3.3V supply and independent communication; replacement MCU is not a sacrificial tester. Preserve results individually.
- [ ] Verify regulator outputs, power sequencing, I2C pull-ups/logic voltages and inactive EN behavior; no motor power during initial tests.
- [ ] Draw/review electrical schematic including power/disable paths, ERC, layout/DRC and 1:1 fit check before production PCB release. For perfboard, review the actual point-to-point solder plan and unpowered continuity instead.
- [ ] Prepare separately versioned firmware pin changes and fault handling; preserve captured/LKG sources; validate build and non-motion tests first.
- [ ] Only then isolated motor/stop tests; log hardware, firmware/build, supply and result. All motor work is currently paused by owner instruction.

### Sources and review

- [Espressif WROOM-1/1U datasheet, Tables 1-1 and 3-1; boot configuration](https://www.espressif.com/sites/default/files/documentation/esp32-s3-wroom-1_wroom-1u_datasheet_en.pdf).
- [Raspberry Pi official header documentation](https://www.raspberrypi.com/documentation/computers/raspberry-pi.html#gpio-and-the-40-pin-header).
- [DFRobot FIT1035 specification: encoder supply and connector](https://wiki.dfrobot.com/fit1035/).
- [DFRobot DRI0058 specification: EN and auxiliary supply](https://wiki.dfrobot.com/dri0058).
- [Analog Devices MAX98357A/MAX98357B datasheet](https://www.analog.com/media/en/technical-documentation/data-sheets/MAX98357A-MAX98357B.pdf) — speaker/channel circuitry must match actual module.

Copilot Pro CLI supplied a bounded review (1.76 AI credits, no file changes). Its claimed numeric GPIO collision between Pi and ESP and claimed contradiction between common ground and USB power were rejected: different MCUs have distinct GPIOs, and intentional common ground is compatible with USB. Pull-up, power-sequencing, EN/boot and missing-footprint concerns were retained for primary review. No assistant review is hardware verification.

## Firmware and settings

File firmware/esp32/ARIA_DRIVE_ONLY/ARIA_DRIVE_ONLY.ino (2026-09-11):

#include <Arduino.h>
#include <Wire.h>
#include <SimpleFOC.h>

// =====================================================
// ARIA ESP32-S3 DRIVE V0.3
// 2x FIT1035 + 2x AS5600 + HEARTBEAT FAILSAFE
// BNO085 đã chuyển sang Raspberry Pi
// =====================================================

// MOTOR LEFT
#define L_IN1 15
#define L_IN2 16
#define L_IN3 17
#define L_EN  18

// MOTOR RIGHT
#define R_IN1 11
#define R_IN2 12
#define R_IN3 13
#define R_EN  14

// AS5600 LEFT
#define LEFT_SDA 38
#define LEFT_SCL 35

// AS5600 RIGHT
#define RIGHT_SDA 36
#define RIGHT_SCL 37

TwoWire I2C_LEFT  = TwoWire(0);
TwoWire I2C_RIGHT = TwoWire(1);

// ---------------- ENCODERS ----------------

MagneticSensorI2C sensorL = MagneticSensorI2C(AS5600_I2C);
MagneticSensorI2C sensorR = MagneticSensorI2C(AS5600_I2C);

// FIT1035 = 7 pole pairs
BLDCMotor motorL = BLDCMotor(7);
BLDCMotor motorR = BLDCMotor(7);

BLDCDriver3PWM driverL(
  L_IN1, L_IN2, L_IN3, L_EN
);

BLDCDriver3PWM driverR(
  R_IN1, R_IN2, R_IN3, R_EN
);

// ---------------- DRIVE ----------------

float driveSpeed = 8.0f;

enum DriveMode {
  DRIVE_STOP,
  DRIVE_FORWARD,
  DRIVE_BACKWARD,
  DRIVE_LEFT,
  DRIVE_RIGHT
};

DriveMode driveMode = DRIVE_STOP;

// ---------------- FAILSAFE ----------------

unsigned long lastHeartbeat = 0;

const unsigned long HEARTBEAT_TIMEOUT_MS = 500;

bool heartbeatSeen = false;
bool failsafeActive = false;


// =====================================================
// DRIVE TARGET
// =====================================================

void applyDrive() {

  switch (driveMode) {

    case DRIVE_FORWARD:
      motorL.target = driveSpeed;
      motorR.target = driveSpeed;
      break;

    case DRIVE_BACKWARD:
      motorL.target = -driveSpeed;
      motorR.target = -driveSpeed;
      break;

    case DRIVE_LEFT:
      motorL.target = driveSpeed * 0.45f;
      motorR.target = driveSpeed;
      break;

    case DRIVE_RIGHT:
      motorL.target = driveSpeed;
      motorR.target = driveSpeed * 0.45f;
      break;

    default:
      motorL.target = 0;
      motorR.target = 0;
      break;
  }
}


void forceStop() {

  driveMode = DRIVE_STOP;

  motorL.target = 0;
  motorR.target = 0;
}


// =====================================================
// SERIAL COMMANDS
// =====================================================

void handleSerial() {

  while (Serial.available()) {

    char c = Serial.read();

    switch (c) {

      case 'H':
      case 'h':

        lastHeartbeat = millis();
        heartbeatSeen = true;

        if (failsafeActive) {
          failsafeActive = false;
          Serial.println("HEARTBEAT RESTORED");
        }

        break;


      case 'F':
      case 'f':

        driveMode = DRIVE_FORWARD;
        applyDrive();

        Serial.printf(
          "FORWARD speed=%.2f\n",
          driveSpeed
        );

        break;


      case 'B':
      case 'b':

        driveMode = DRIVE_BACKWARD;
        applyDrive();

        Serial.printf(
          "BACKWARD speed=%.2f\n",
          driveSpeed
        );

        break;


      case 'L':
      case 'l':

        driveMode = DRIVE_LEFT;
        applyDrive();

        Serial.printf(
          "LEFT speed=%.2f\n",
          driveSpeed
        );

        break;


      case 'R':
      case 'r':

        driveMode = DRIVE_RIGHT;
        applyDrive();

        Serial.printf(
          "RIGHT speed=%.2f\n",
          driveSpeed
        );

        break;


      case 'S':
      case 's':
      case ' ':

        forceStop();

        Serial.println("STOP");

        break;


      case '+':

        driveSpeed += 2.0f;

        if (driveSpeed > 20.0f)
          driveSpeed = 20.0f;

        applyDrive();

        Serial.printf(
          "SPEED = %.2f\n",
          driveSpeed
        );

        break;


      case '-':

        driveSpeed -= 2.0f;

        if (driveSpeed < 2.0f)
          driveSpeed = 2.0f;

        applyDrive();

        Serial.printf(
          "SPEED = %.2f\n",
          driveSpeed
        );

        break;
    }
  }
}


// =====================================================
// HEARTBEAT FAILSAFE
// =====================================================

void checkHeartbeat() {

  if (!heartbeatSeen)
    return;

  if (
    !failsafeActive &&
    millis() - lastHeartbeat > HEARTBEAT_TIMEOUT_MS
  ) {

    forceStop();

    failsafeActive = true;

    Serial.println(
      "FAILSAFE STOP - HEARTBEAT LOST"
    );
  }
}


// =====================================================
// SETUP
// =====================================================

void setup() {

  Serial.begin(115200);
  delay(1500);

  Serial.println();
  Serial.println("==============================");
  Serial.println("ARIA ESP DRIVE V0.3");
  Serial.println("==============================");

  // Encoder buses
  I2C_LEFT.begin(
    LEFT_SDA,
    LEFT_SCL,
    400000
  );

  I2C_RIGHT.begin(
    RIGHT_SDA,
    RIGHT_SCL,
    400000
  );

  sensorL.init(&I2C_LEFT);
  sensorR.init(&I2C_RIGHT);

  Serial.println("AS5600 LEFT READY");
  Serial.println("AS5600 RIGHT READY");

  // Driver power
  driverL.voltage_power_supply = 12.0;
  driverR.voltage_power_supply = 12.0;

  driverL.voltage_limit = 3.0;
  driverR.voltage_limit = 3.0;

  driverL.init();
  driverR.init();

  // Motors
  motorL.linkSensor(&sensorL);
  motorR.linkSensor(&sensorR);

  motorL.linkDriver(&driverL);
  motorR.linkDriver(&driverR);

  motorL.controller =
    MotionControlType::velocity;

  motorR.controller =
    MotionControlType::velocity;

  motorL.voltage_limit = 3.0;
  motorR.voltage_limit = 3.0;

  motorL.velocity_limit = 20.0;
  motorR.velocity_limit = 20.0;

  motorL.voltage_sensor_align = 1.5;
  motorR.voltage_sensor_align = 1.5;

  // PID LOCKED - bản đã PASS
  motorL.PID_velocity.P = 0.15;
  motorL.PID_velocity.I = 1.0;
  motorL.PID_velocity.D = 0.0;

  motorR.PID_velocity.P = 0.15;
  motorR.PID_velocity.I = 1.0;
  motorR.PID_velocity.D = 0.0;

  motorL.PID_velocity.output_ramp = 500;
  motorR.PID_velocity.output_ramp = 500;

  motorL.LPF_velocity.Tf = 0.02;
  motorR.LPF_velocity.Tf = 0.02;

  motorL.foc_modulation =
    FOCModulationType::SpaceVectorPWM;

  motorR.foc_modulation =
    FOCModulationType::SpaceVectorPWM;

  Serial.println("MOTOR INIT");

  motorL.init();
  motorR.init();

  Serial.println("FOC ALIGN");

  motorL.initFOC();
  motorR.initFOC();

  forceStop();

  Serial.println("FOC READY");
  Serial.println("==============================");
}


// =====================================================
// LOOP
// =====================================================

void loop() {

  motorL.loopFOC();
  motorR.loopFOC();

  motorL.move();
  motorR.move();

  handleSerial();

  checkHeartbeat();
}

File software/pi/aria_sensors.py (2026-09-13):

#!/usr/bin/env python3
"""Standalone Raspberry Pi sensor monitor for Project ARIA.

This program intentionally has no ESP32, motor, encoder, driver, service, camera,
microphone, or audio control code.
"""

from __future__ import annotations

import argparse
import json
import math
import os
import sys
import tempfile
import time
from datetime import datetime, timezone
from pathlib import Path
from typing import Any


XSHUT_PINS = (22, 23, 24, 25)
TOF_ADDRESSES = (0x30, 0x31, 0x32, 0x33)
BNO_ADDRESS = 0x4A
BME_ADDRESS = 0x76
INA_ADDRESS = 0x40


def utc_timestamp() -> str:
    return datetime.now(timezone.utc).isoformat(timespec="milliseconds").replace(
        "+00:00", "Z"
    )


def error_text(exc: BaseException) -> str:
    text = str(exc).strip()
    return f"{type(exc).__name__}: {text}" if text else type(exc).__name__


class SensorMonitor:
    def __init__(self, *, tof_timeout: float = 0.25) -> None:
        self.tof_timeout = tof_timeout
        self.i2c: Any = None
        self.xshut: list[Any] = []
        self.tof: list[Any | None] = [None] * len(TOF_ADDRESSES)
        self.bme: Any = None
        self.bno: Any = None
        self.ina: Any = None
        self.init_errors: dict[str, str] = {}

    def initialize(self) -> None:
        """Initialize the shared Pi I2C bus and every sensor independently."""
        try:
            import board

            self.i2c = board.I2C()
        except Exception as exc:
            detail = error_text(exc)
            self.init_errors["i2c"] = detail
            for name in ("tof1", "tof2", "tof3", "tof4", "bme280", "bno085", "ina260"):
                self.init_errors[name] = f"I2C unavailable: {detail}"
            return

        self._initialize_bno()
        self._initialize_bme()
        self._initialize_ina()
        self._initialize_tof()

    def _initialize_tof(self) -> None:
        try:
            import adafruit_vl53l1x
            from gpiozero import DigitalOutputDevice

            for pin in XSHUT_PINS:
                self.xshut.append(
                    DigitalOutputDevice(pin, active_high=True, initial_value=False)
                )
        except Exception as exc:
            detail = error_text(exc)
            for index in range(len(TOF_ADDRESSES)):
                self.init_errors[f"tof{index + 1}"] = f"XSHUT setup failed: {detail}"
            return

        for pin in self.xshut:
            pin.off()
        time.sleep(0.20)

        for index, (pin, address) in enumerate(zip(self.xshut, TOF_ADDRESSES)):
            name = f"tof{index + 1}"
            try:
                pin.on()
                time.sleep(0.15)
                sensor = adafruit_vl53l1x.VL53L1X(self.i2c, address=0x29)
                sensor.set_address(address)
                sensor.distance_mode = 2
                sensor.timing_budget = 100
                sensor.start_ranging()
                self.tof[index] = sensor
            except Exception as exc:
                self.init_errors[name] = error_text(exc)
                self.tof[index] = None
                # Prevent a failed device remaining at 0x29 from colliding with
                # the next VL53L1X brought out of shutdown.
                try:
                    pin.off()
                except Exception:
                    pass

    def _initialize_bme(self) -> None:
        try:
            from adafruit_bme280 import basic

            self.bme = basic.Adafruit_BME280_I2C(self.i2c, address=BME_ADDRESS)
        except Exception as exc:
            self.init_errors["bme280"] = error_text(exc)

    def _initialize_bno(self) -> None:
        try:
            from adafruit_bno08x import BNO_REPORT_ACCELEROMETER
            from adafruit_bno08x.i2c import BNO08X_I2C

            self.bno = BNO08X_I2C(self.i2c, address=BNO_ADDRESS)
            self.bno.enable_feature(BNO_REPORT_ACCELEROMETER)
        except Exception as exc:
            self.init_errors["bno085"] = error_text(exc)
            self.bno = None

    def _initialize_ina(self) -> None:
        try:
            import adafruit_ina260

            self.ina = adafruit_ina260.INA260(self.i2c, address=INA_ADDRESS)
        except Exception as exc:
            self.init_errors["ina260"] = error_text(exc)

    def _unavailable(self, name: str) -> dict[str, Any]:
        return {
            "status": "error",
            "error": self.init_errors.get(name, "not initialized"),
        }

    def read_tof(self) -> list[dict[str, Any]]:
        results: list[dict[str, Any] | None] = [None] * len(self.tof)
        pending = {index for index, sensor in enumerate(self.tof) if sensor is not None}

        for index, sensor in enumerate(self.tof):
            if sensor is None:
                results[index] = self._unavailable(f"tof{index + 1}")

        deadline = time.monotonic() + self.tof_timeout
        first_poll = True
        while pending and (first_poll or time.monotonic() < deadline):
            first_poll = False
            for index in tuple(pending):
                sensor = self.tof[index]
                try:
                    if not sensor.data_ready:
                        continue
                    distance_cm = sensor.distance
                    sensor.clear_interrupt()
                    if distance_cm is None:
                        results[index] = {"status": "no_data", "distance_mm": None}
                    else:
                        results[index] = {
                            "status": "ok",
                            "distance_mm": round(float(distance_cm) * 10.0, 1),
                        }
                    pending.remove(index)
                except Exception as exc:
                    results[index] = {"status": "error", "error": error_text(exc)}
                    pending.remove(index)
            if pending:
                time.sleep(0.005)

        for index in pending:
            results[index] = {"status": "timeout", "distance_mm": None}

        return [result for result in results if result is not None]

    def read_bme(self) -> dict[str, Any]:
        if self.bme is None:
            return self._unavailable("bme280")
        try:
            return {
                "status": "ok",
                "temperature_c": round(float(self.bme.temperature), 2),
                "humidity_percent": round(float(self.bme.relative_humidity), 1),
                "pressure_hpa": round(float(self.bme.pressure), 1),
            }
        except Exception as exc:
            return {"status": "error", "error": error_text(exc)}
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

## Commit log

2026-07-25 docs: draft Sprint 1 hardware architecture and BOM
2026-07-26 docs: consolidate Sprint 2 hardware baseline
    * docs: draft Sprint 1 hardware architecture and BOM
    * docs: freeze Sprint 2 hardware baseline
    * docs: consolidate Sprint 2 hardware baseline
2026-07-26 docs: synchronize ARIA hardware freeze and CAD baseline
    [ARIA-CAM-001_Camera-Module-3-Wide-NoIR.dwg, ARIA-CPU-001_Raspberry-Pi-5_Active-Cooler.dwg, ARIA-MCU-001_ESP32-S3-DevKitC-1.dwg]
2026-09-11 docs: replace current INA226 inventory with two INA260 boards
    Set canonical power sensing to 2 x INA260 current/voltage/power monitor boards, DigiKey 1528-2955-ND, board code 4226. Update inventory date and physical-unit total to 29.
    Pre-commit repository audit: one current INA226 reference in purchased-hardware/README.md; no historical INA226 references or changelog in the current tree. Wiring, sensor-related and firmware documentation contains no stale INA226 references and points to the canonical inventory. Preserve existing Git history.
2026-09-11 docs: canonicalize current ARIA hardware in ARIA-BOM-001
    Record two working MAX98357A boards, current gravel wheel dimensions and integrated battery BMS. Preserve INA260 identity and quantity; migrate the single inventory to docs/ARIA-BOM-001.md and update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
2026-09-11 chore: consolidate captured ARIA Pi and ESP32 sources with canonical handoff
2026-09-11 docs: reconcile KST step plan with current ARIA evidence
2026-09-11 docs: record hardware confirmation and wiring audit
2026-09-11 docs: clarify INA260 pending delivery and unassigned wiring
2026-09-11 docs: reconcile signal wiring and current roadmap checkpoint
2026-09-12 docs: record 70x100 base and segregated common-edge power banks
2026-09-12 cad: add illustrative stacked module STEP models for SolidWorks
    [ARIA_STACK_R3_ASSEMBLED_CONCEPT.step, ARIA_STACK_R3_EXPLODED_CONCEPT.step]
2026-09-12 cad: initialize Coin binding for unclipped concept previews
2026-09-12 Add right encoder diagnostic for replacement N16R8 and record Pi evidence
    [ARIA_ENCODER_CHECK_R1.ino]
2026-09-12 Record Pi serial bridge and diagnostic UART build option
2026-09-12 Save Pi sensor audio evidence and cross-task continuity rules
2026-09-12 Add standalone Pi sensor monitor
2026-09-13 docs: sync Pi audio followup and owner-reported power routing
2026-09-13 feat: add simple ARIA standby face clock and temperature
2026-09-13 style: switch ARIA preview to female avatar
2026-09-13 Give avatar softer facial depth and eye materials
2026-09-13 Add editable ARIA character draft and isolated 3D preview
    [aria-concept-01-draft.blend]
2026-09-13 Refine avatar proportions complexion and hair surface detail
    [aria-concept-01-draft.blend]
2026-09-13 Verify existing Blender and prepare custom sculpt reference workspace
    [aria-custom-sculpt.blend]
2026-09-13 Prepare isolated MPFB setup and editable human base
    [aria-human-base.blend]
2026-09-13 Create editable head proportion study with clay review renders
    [aria-head-blockout-r1.blend]
2026-09-13 Add R2 static eyes and eyelid profile refinement
    [aria-head-r2.blend]
2026-09-13 Add R3 brows and static eyelid details preserving accepted face
    [aria-head-r3.blend]
2026-09-13 Thicken character brows in preserved R4 revision
    [aria-head-r4.blend]
2026-09-13 Increase brow width and dark coverage in R5
    [aria-head-r5.blend]
2026-09-13 feat(avatar): create editable Blender head study after R6 rejection
    [aria-head-r7.blend]
2026-09-13 Checkpoint incomplete reference-fitted Blender appearance studies R8-R18
    [aria-head-r10.blend, aria-head-r11.blend, aria-head-r12.blend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]
2026-09-13 Preserve incomplete Blender likeness iterations R19-R26 and visual review
    [aria-head-r19.blend, aria-head-r20.blend, aria-head-r21.blend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]
2026-09-14 avatar(concept01): smooth face and hair boundary pass
    [aria-concept-01-draft.blend]
